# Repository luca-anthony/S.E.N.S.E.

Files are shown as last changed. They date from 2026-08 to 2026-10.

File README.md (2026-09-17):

<h1>ABSTRACT</h1>

This project started when we were scrambling for ideas for the Science Fair. We weren’t exactly sure what we were going to do. We considered projects on radiation, contamination, and physics. We just weren’t sure what to do. We thought of our past experiences and what we could turn into a project that could help someone. One of our team members was blind for a certain amount of time. They had a hard time navigating through the world and even just picking things up without knocking them over. We thought about how many other people must deal with these problems, so we came up with an idea to fix it. We thought of a wearable device that would be able to help people overcome these obstacles. So we made S.E.N.S.E. Using ToF sensors, IMUs, and a microcontroller, we were able to fit a device that can help people navigate through the world and their home that is just the size of a glove. So with this, we present S.E.N.S.E., Spatial Echo Navigation & Sensing Equipment. The tool you can use to travel the world, that is just the size of your hand.

<h1>How to Use</h1>

If you want to make this yourself, should you see this, or if you just want to do something for fun, this is how. 

<h4>For Raspberry Pi Zero 2 W</h4>
Commands for Pi: 

sudo apt update && sudo apt install git -y \
git clone https://github.com/luca-anthony/S.E.N.S.E./ \
cd S.E.N.S.E./Code/Bash && chmod +x setup.sh && ./setup.sh 

After installing everything, look in the Code/Python for the config.py file and follow the steps for wiring.

<h4>NOTE:</h4>

The team has decided against using the Raspberry Pi Zero 2 W.\
Any code or files for this Micro-Computer is not going to be updated as of 11 September 2026.

<h1>Contributions and Thanks</h1>

<h4>Donations and Funding</h4>

Logan Anthony - $30 \
(DEV) Kumar Nandi - $50 \
(DEV) Lou Anthony - $50 \
Reese Green - $1

To all of the people who donated or contributed to the project and or ENLIGHTEN, from the bottom of our hearts, <i>thank you</i>.

We are ENLIGHTEN. \
To bring more light to the world. 

<h1>STUFF FOR SCIENCE FAIR</h1>

<b>This section is irrelevant to anyone who is not a student or teacher at our school or who is not a direct contributor to S.E.N.S.E.</b>

Below is the link to the Science Fair Submission Form: \
<a href="https://docs.google.com/document/d/1qRC2OpuflSs2WIL9HmuddMR0fpJTnckwT1Jk4RrbsxM/edit?usp=sharing">Document</a>

Below is the link to the Final Research Paper and the drafts. \
<a href="https://docs.google.com/document/d/1NYGTEB_40bhyAXyYJ5kPaozn24XC8YlPzl25bhtnPuw/edit?usp=sharing">Document(s)</a>

If you want to donate or look in funding parts of this project text or call +1 (210) 865-7632 to discuss the matter.

<h4>Developers</h4>

Lou O. Anthony, lead scientist, lead computer scientist, assistant engineer, \
Kumar Nandi, lead engineer, lead 3D and 2D modeler, assistant computer scientist, \
Ty L. Garay, lead visionary, assistant 3D and 2D modeler, assistant engineer

<h1>EXTRAS</h1>

The website is no longer being updated as of 6 September 2026. \
It was purely a fun break for the team, not actually meant to present information.

<b>In Loving Memory of Anthony Garay</b> \
<b>You would’ve loved this</b>

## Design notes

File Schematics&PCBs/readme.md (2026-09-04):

Meant for schematics and PCBs. Pretty self explanatory.

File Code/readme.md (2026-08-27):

The C and C++ directories are meant for if we use the XIAO ESP32 C3\
The Python directory is meant for if we use the Raspberry Pi 2 Zero W

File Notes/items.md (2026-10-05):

REMOVED<sup>[1]</sup>\
VL53L1X<sup>[2]</sup> $14.99USD \
REMOVED<sup>[3]</sup> \
1027 Coin Cell Vibration Motor<sup>[4]</sup> $6.99USD \
2N2222 NPN Transistor(s)<sup>[5]</sup> $9.99USD \
1kΩ Resistor<sup>[6]</sup> $3.99USD \
LSM6DS3TR-C IMU unit<sup>[7]</sup> $9.95USDx2 \
1N4001 Diode<sup>[8]</sup> $4.74USD \
Raspberry Pi Pico<sup>[9]</sup> $9.99USD\
Sunlu TPU 95A Filament<sup>[10]</sup> $30.99USD \
Sunlu ASA Filament<sup>[11]</sup> $25.99USD \
Winfox 3.7V 2000mAh 803040 LiPo Battery<sup>[12]</sup> $7.99USDx2 \
Bourns Inc. MF-R050-ND PPTC Fuse<sup>[13]</sup> $9.99USD \
WWZMDiB 840 Pin Breadboard Jumper Wires Kit<sup>[14]</sup> $8.99USD \
Rindion 32 Pcs PCB Boards<sup>[15]</sup> $7.99USD\
Soldering Iron and Solder of your choice \
3D Printer of your choice (enclosed printer or enclosure recommended)

<h3>TOTAL</h3>

$172.92 USD (Not including tax or shipping) \
$118.54 USD (Without filament, Not including tax or shipping)

<a href="">REMOVED<sup>[1]</sup></a>\
<a href="https://www.amazon.com/dp/B09V4DS888?lv=shuf&channelId=500&plpRedirect=mhFallback">Distance sensors<sup>[2]</sup>\
<a href="">REMOVED<sup>[3]</sup><la>\
<a href="https://www.amazon.com/dp/B0993GDD7N?ref=clp_hp_h_pc&th=1">1027 Coin Cell Vibration Motor<sup>[4]</sup></a>\
<a href="https://www.amazon.com/BOJACK-General-Purpose-Transistors-Assortment/dp/B07T61SY9Y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">2N2222 NPN Transistor<sup>[5]</sup></a>\
<a href="https://www.amazon.com/California-JOS-Tolerance-Resistor-Resistance/dp/B0BDKV2TY5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">1kΩ Resistor<sup>[6]</sup>\
<a href="https://www.adafruit.com/product/4503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">IMU unit<sup>[7]</sup></a>\
<a href="https://www.amazon.com/EEEEE-1N4001-Rectifier-Electronic-Silicon/dp/B0FC2CTBJR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">1N4001 Diode<sup>[8]</sup></a>\
<a href="https://www.amazon.com/Raspberry-Pi-Pico/dp/B09KVB8LVR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">Raspberry Pi Pico<sup>[9]</sup></a>\
<a href="https://www.amazon.com/SUNLU-TPU-Filament-1-75mm-Flexible/dp/B0BXNWK6NS?th=1">Sunlu TPU 95A filament<sup>[10]</sup></a>\
<a href="https://www.amazon.com/SUNLU-ASA-Filament-3D-Printer/dp/B0B18CQGQJ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">Sunlu ASA filament<sup>[11]</sup></a> \
<a href="https://www.amazon.com/Winfox-Rechargeable-Connector-Bluetooth-Portable/dp/B0GDQVRHHZ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">Battery<sup>[12]</sup></a> \
<a href="https://www.amazon.com/gp/product/B085RDTCCV/ref=sw_img_1?smid=&th=1">Fuses<sup>[13]</sup></a> \
<a href="https://www.amazon.com/gp/product/B0BWGZRGYP/ref=ewc_pr_img_2?smid=A1YZW40LYQY3L1&psc=1">Wires<sup>[14]</sup></a> \
<a href="https://www.amazon.com/gp/product/B0DBZ1BXFZ/ref=ewc_pr_img_1?smid=A1Z1ENBD0KSZ4W&psc=1">PCBs<sup>[15]</sup></a>

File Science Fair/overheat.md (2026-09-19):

To ensure that the device would not overheat and harm the user, we thought of many things that could happen, including overheating due to air temperature, magnetic fields, and in case it touched something hot. Below is the math we used to ensure overheating would not happen. For this, we mainly used Maxwell's equations.

$$P = I^2 R \qquad B = \frac{\mu_0 I}{2\pi r} \qquad P_{\text{net}} = \epsilon\sigma A(T_{\text{source}}^4 - T_{\text{cap}}^4)$$

$$I = 0.015 \qquad T_{\text{source}} = 318.15 \qquad T_{\text{cap}} = 218.15 \qquad A = 4.9 \times 10^{-5}$$

$$B = \frac{(4\pi 10^{-7})0.015}{2\pi 0.003} \approx 6.67 \times 10^{-6} \text{ Tesla }(0.066 \text{ Gauss})$$

$$P_{\text{net}} = 0.09(5.67 \times 10^{-8}) \times (4.9 \times 10^{-5}) \times (318.15^4 - 218.15^4)$$

$$P_{\text{net}} \approx 5.9 \times 10^{-6} \text{ Watts }(5.9\mu\text{w})$$

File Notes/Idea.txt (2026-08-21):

PROJECT TITLE: HaptiSight - Multi-Array Wearable Spatial-Depth-to-Tactile Interface for Visually Impaired Navigation

1. PROJECT OVERVIEW AND HYPOTHESIS
Standard white canes and guide dogs leave a critical gap: they primarily identify ground-level obstacles directly in front of the user. Head-height hazards (low tree branches, signposts, open cabinet doors, suspended overhangs) remain undetectable until contact occurs. Existing electronic travel aids (ETAs) often rely on single-point ultrasonic sensors that trigger audio beeps. Audio alerts pollute critical environmental hearing cues, while single-point measurements fail to convey spatial context or object geometry.

This project develops an integrated wearable system (a chest harness or forearm sleeve) featuring a 3x3 matrix of Time-of-Flight (ToF) distance sensors paired with a corresponding 3x3 matrix of haptic vibration motors. By mapping 3D spatial depth arrays into real-time tactile intensity and frequency patterns on the skin, the device translates environmental geometry into touch perception without requiring visual sight or compromising hearing.

Hypothesis: Implementing a non-linear, edge-detecting haptic mapping algorithm will reduce obstacle navigation times and collision frequencies by at least 40% compared to traditional linear single-sensor distance-to-vibration feedback mechanisms.

2. HARDWARE AND SYSTEM ARCHITECTURE (ENGINEERING TEAM)
The engineering team handles component selection, power distribution, circuit design, signal multiplexing, and wearable ergonomics.

A. Microcontroller Unit (MCU):

* Primary MCU: ESP32-S3 or Teensy 4.1. Preferred due to high clock speeds, hardware I2C/SPI buses, low power consumption, and dual-core processing capabilities (allowing core 0 to process sensor inputs while core 1 manages haptic motor outputs).

B. Sensor Matrix (3x3 Grid):

* Sensor Type: VL53L1X Time-of-Flight (ToF) laser-ranging sensors (or Ultrasonic JSN-SR04T / MB1010 for wider cone sensing).
* Arrangement: 3 rows by 3 columns mounted on a rigid/flexible chest matrix covering three elevation zones:
* Top Row (3 sensors): Overhead and head-height field-of-view (1.5 m to 2.2 m above ground).
* Middle Row (3 sensors): Mid-torso and waist-height field-of-view (0.7 m to 1.5 m).
* Bottom Row (3 sensors): Low-level hazards, steps, and curbs (0 m to 0.7 m).

* Multiplexing: Since VL53L1X sensors share a default I2C address, use a TCA9548A 8-channel I2C multiplexer (or two multiplexers daisy-chained) to query each sensor rapidly without address conflicts.

C. Haptic Actuator Array:

* Motors: Linear Resonant Actuators (LRAs) or Eccentric Rotating Mass (ERM) coin vibration motors (e.g., 10mm x 2.0mm).
* Drivers: DRV2605L haptic motor driver chips connected via I2C, or transistor/MOSFET driver arrays (e.g., ULN2003 or custom MOSFET gates) controlled via Pulse-Width Modulation (PWM).
* Layout: Worn against a skin surface with high tactile resolution, such as the inner forearm, upper chest, or upper back.

D. Power Management & Mechanicals:

* Power: 3.7V LiPo battery (2000mAh+) feeding a step-up/step-down buck boost regulator supplying clean 3.3V and 5.0V rails.
* Chassis: Custom 3D-printed modular sensor housing featuring 15-degree angled mounts for the top and bottom sensor rows to maximize vertical field-of-view.

3. SOFTWARE AND ALGORITHMIC DESIGNS (CODING TEAM)
The coding team handles signal acquisition, noise filtering, spatial algorithms, and haptic rendering curves.

A. Data Pipeline and Filtering:

1. Matrix Polling: Continuous sequential polling of all 9 sensors via the I2C multiplexer at a target refresh rate of 30 Hz to 50 Hz.
2. Noise Suppression: Apply a moving median filter combined with a low-pass exponential filter to remove false reflections, specular noise, and outdoor sun-glare anomalies.

B. Experimental Feedback Algorithms (To Be Compared):

* Mode 1: Linear Direct Distance Mapping
* Formula: V_out = V_max * (1 - (D_measured / D_max))
* Vibration intensity scales proportionally with distance. Simple, but quickly leads to skin desensitization.

* Mode 2: Logarithmic Skin-Adapted Scaling
* Human tactile perception follows Weber-Fechner laws (non-linear sensitivity).
* Formula: V_out = V_max * (log(D_max / max(D_measured, D_min)) / log(D_max / D_min))
* Provides subtle feedback for distant objects while rapidly ramping up intensity as an obstacle enters the immediate safety zone (under 1 meter).

* Mode 3: Velocity-Sensitive Closure Rate Mode
* Calculates delta distance over time (dD/dt).
* Actuators remain silent for stationary distant objects, but activate with high intensity if the rate of closure toward an obstacle indicates imminent collision.

* Mode 4: Spatial Edge & Silhouette Detection
* The MCU calculates spatial gradients across neighboring matrix cells: G_x = |D(x+1, y) - D(x, y)| and G_y = |D(x, y+1) - D(x, y)|.
* Vibrate actuators only where a significant depth discontinuity occurs, allowing the wearer to feel the boundary, door opening, or outline of an object.

4. EXPERIMENTAL TESTING METHODOLOGY (SCIENCE FAIR DATA)
To qualify as an advanced science fair submission, quantitative performance metrics must be collected across multiple experimental trials.

A. Variables:

* Independent Variable: Haptic algorithm type (Linear, Logarithmic, Velocity-Sensitive, Edge-Detection) and sensor configuration.
* Dependent Variables:
1. Time to navigate a standardized 15-meter obstacle course (seconds).
2. Total number of physical collisions (head, torso, ground).
3. Spatial recognition accuracy (percentage of correct identification of mock obstacles: doorway, pole, low hanging branch, box on floor).

* Controlled Variables: Course layout, obstacle dimensions, walking path width, ambient lighting, and ear protection/masking noise worn by subjects to prevent reliance on acoustic echoes.

B. Testing Protocol:

1. Construct a standardized, repeatable indoor/outdoor maze containing 10 hazards (3 head-height, 4 torso-height, 3 ground-level).
2. Run trials with blindfolded test participants across each feedback mode (minimum 10 trials per mode per participant).
3. Record time, collisions, and subjective spatial mapping accuracy ratings.
4. Calculate statistical significance using ANOVA or paired T-tests to determine which algorithm offers the best balance of speed, safety, and cognitive load reduction.
5. REQUIRED COMPONENTS AND SHOPPING LIST

* Microcontroller: ESP32-S3 Dev Board or Teensy 4.1
* Distance Sensors: 9x VL53L1X Time-of-Flight sensors
* I2C Multiplexer: 2x TCA9548A modules
* Haptic Drivers: 9x DRV2605L breakout boards (or custom MOSFET driver board)
* Haptic Motors: 9x ERM coin vibration motors (10mm)
* Power: 3.7V 2500mAh LiPo battery + TP4056 charging board + 5V step-up boost converter
* Framing: Flexible chest harness/vest, 3D printing filament (PLA/TPU), jumper wires, breadboards/perfboards

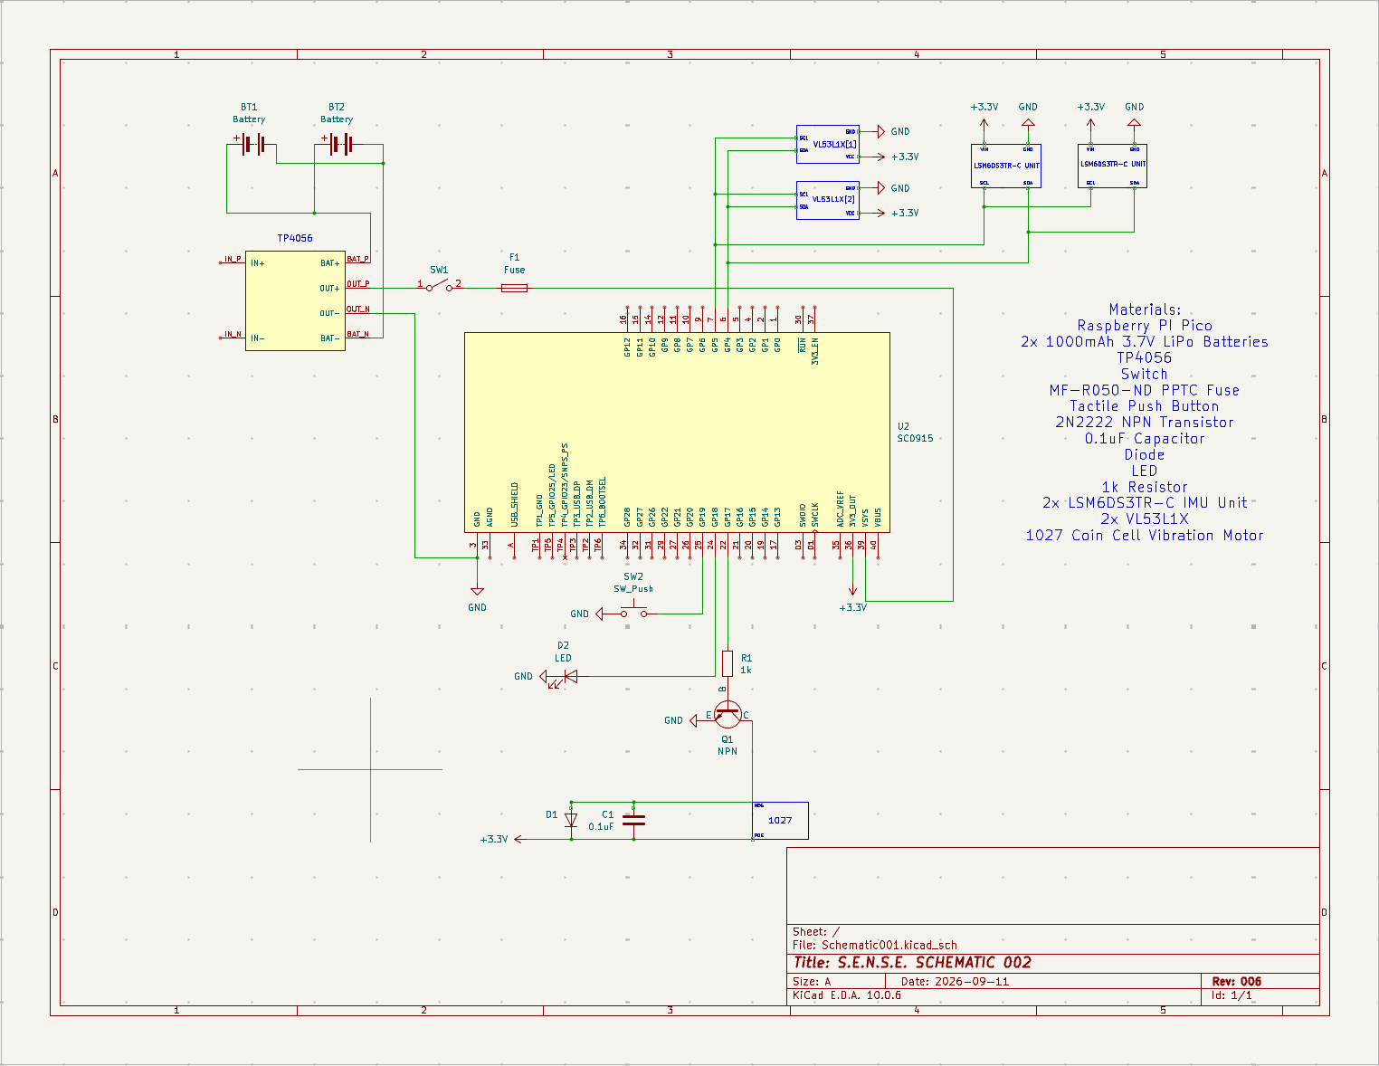
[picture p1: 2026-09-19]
Schematics&PCBs/Schematic001/schematic001_kicad_Schematic001.png

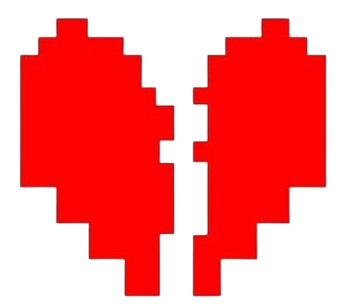
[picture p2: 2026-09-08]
Website/assets/heart_broken.png

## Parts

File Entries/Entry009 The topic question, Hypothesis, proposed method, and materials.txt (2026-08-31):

We need to discuss quite a few things. 
The topic question/problem, hypthesis, proposed method, and materials. 
Let's start with the topic question/problem. 

Humans who have visual impairment struggle with picking things up walking or normal functions. 
About half of the human brain works to process visual information. 
With visual impairment, things like walking and even picking things up. 
We want to solve that.
So that is our problem. How can we better help that part of the community with visual impairments?

Let's move to the Hypothesis. 
Since we decided to use coin cell vibration sensors to help direct people, how can the sensors and motors help people?
I created a few hypotheses. 

If the human body can detect vibrations, then can they use vibrations to navigate and do tasks? 

Now lets talk about our proposed method.
Entry No.4 talks about the proposed method of testing.
I think the best thing is to test both. 
If we test in both ways we not only test how to walk, but also tasks like picking things up. 
Therefore we need to test not just idea No. 1 but also idea No.2. 

Now, the designing. 
In the notes section we have the items list. 
The most expensive thing is the filaments. 
In total with our current items list, we are running about 50-80 dollars. 
This means that this is within our budget.
  As for designing it, that will be done in Fusion360 in a free plan. 
They will be printed on two Bambu Lab printers. 

Conclusion: This project is within our budget, easily doable and definetly will help a lot of people. 

Kumar N. -Lead 3d modeler, lead engineer, assistant computer scientist.

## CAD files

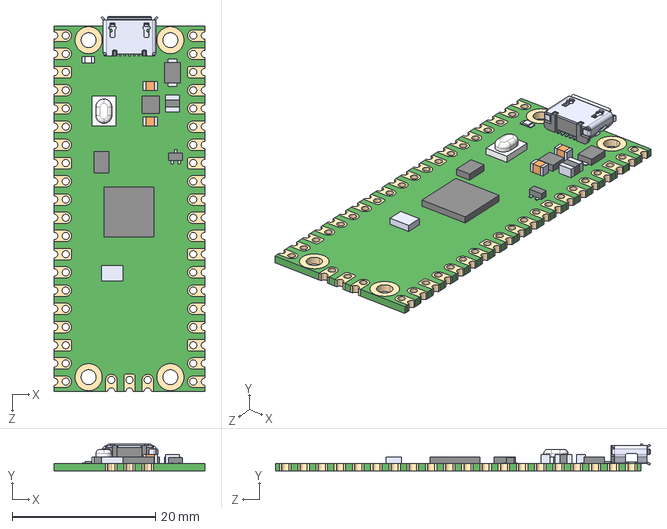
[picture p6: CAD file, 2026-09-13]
Schematics&PCBs/Schematic001/SC0915 - RPP/SC0915.step
21.0 x 3.73 x 52.3 mm

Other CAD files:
Models/Model 5.f3d
Models/Wristband Model 3.f3d
Models/Wristband Model 4.f3d
Models/Wristband and components model 2.f3d
Models/wristband and components.f3d

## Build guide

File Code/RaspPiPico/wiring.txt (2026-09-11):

==================================
        PICO 2 W WIRING CHART
==================================

----------------------------------
      POWER & I2C SHARED BUS
----------------------------------
* I2C Bus: Using I2C0 hardware bus.
  - SDA (GP4) and SCL (GP5) are shared across the VL53L1X, 
    IMU #1, and IMU #2 in parallel.
* Power Rails:
  - 3.3V Rail: Pin 36 (3V3 OUT)
  - 5V Rail: Pin 40 (VBUS - raw USB 5V for motor)
  - GND Rail: Any GND pin (Pins 3, 8, 13, 18, 23, 28, 33, 38)

----------------------------------
              VL53L1X
----------------------------------
VCC --> Pin 36 / 3V3 OUT
GND --> Pin 3  / GND
SDA --> Pin 6  / GP4 (I2C0 SDA)
SCL --> Pin 7  / GP5 (I2C0 SCL)

----------------------------------
        IMU #1 (Hand Back)
----------------------------------
VCC --> Pin 36 / 3V3 OUT
GND --> Pin 8  / GND
SDA --> Pin 6  / GP4 (I2C0 SDA)
SCL --> Pin 7  / GP5 (I2C0 SCL)
AD0 --> Pin 8  / GND            (Sets I2C Address to 0x68)

----------------------------------
        IMU #2 (Finger Tip)
----------------------------------
VCC --> Pin 36 / 3V3 OUT
GND --> Pin 13 / GND
SDA --> Pin 6  / GP4 (I2C0 SDA)
SCL --> Pin 7  / GP5 (I2C0 SCL)
AD0 --> Pin 36 / 3V3 OUT        (Sets I2C Address to 0x69)

----------------------------------
      MOTOR / TRANSISTOR / DIODE
----------------------------------
----TRANSISTOR (NPN / e.g. PN2222)
EMITTER   --> Pin 18 / GND
BASE      --> 1K Resistor
1K R      --> Pin 22 / GP17 (PWM control)
COLLECTOR --> MOTOR NEG / DIODE ANODE

----DIODE (Flyback)
CATHODE   --> Pin 40 / VBUS (5V USB Power)
ANODE     --> COLLECTOR / MOTOR NEG

----MOTOR (ERM Vibration Coin)
POS       --> Pin 40 / VBUS (Connected to Diode Cathode)
NEG       --> COLLECTOR / DIODE ANODE

----------------------------------
            STATUS LED
----------------------------------
ANODE (+) --> 220Ω Resistor
220Ω R    --> Pin 24 / GP18
CATHODE(-)--> Pin 23 / GND

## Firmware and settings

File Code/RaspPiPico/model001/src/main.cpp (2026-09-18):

#include <Arduino.h>
#include <Wire.h>
#include <Adafruit_VL53L1X.h>
#include <Preferences.h>
#include "SparkFunLSM6DS3.h"

//======================
// INPUTS AND VARIABLES
//======================
const int MOT_IO = 17;
const int LED_IO = 18;
const int BTN_IO = 19;

const int DIST_THRESH = 100;
const int16_t CHANGE_THRESH = 196;

const int MOT_MIN_PWM = 100;
const int MOT_MAX_PWM = 255;

const unsigned long SENSOR_INTERVAL_MS = 50;   // how often to poll sensors
const unsigned long DEBOUNCE_MS        = 200;  // button debounce window
const float DISTANCE_SMOOTHING_ALPHA   = 0.35; // 0=very smooth/slow, 1=raw/instant

#define IRQ_PIN -1
#define XSHUT_PIN -1

#undef Wire
arduino::MbedI2C Wire(4, 5);

Adafruit_VL53L1X sensor = Adafruit_VL53L1X();

//======================
//       GLOBALS
//======================
Adafruit_VL53L1X vl53 = Adafruit_VL53L1X(XSHUT_PIN, IRQ_PIN);
LSM6DS3 myIMU(I2C_MODE, 0x6A);
Preferences prefs;

int mode = 1; // 1 = navigation, 2 = close-range
float smoothedDistanceCM = -1;      // -1 means "no valid reading yet"

unsigned long lastSensRead = 0;
unsigned long lastDebounceTime = 0;
int16_t distance = 0;

int lastButtonReading = HIGH; // pull=up idle state
int lastButtonState = HIGH; 

//---------------------------------------------------------------
// Haptic feedback patterns
// Kept short/blocking since these only fire on discrete events
// (boot, mode switch), not during normal obstacle sensing.
//---------------------------------------------------------------
void buzz(int durationMs, int intensity = MOT_MAX_PWM) {
  analogWrite(MOT_IO, intensity);
  delay(durationMs);
  analogWrite(MOT_IO, 0);
}

void buzzPattern(int count, int durationMs = 120, int gapMs = 120) {
  for (int i = 0; i < count; i++) {
    buzz(durationMs);
    if (i < count - 1) delay(gapMs);
  }
}

// One buzz = mode 1 (navigation), two buzzes = mode 2 (close-range).
void announceMode() {
  buzzPattern(mode);
}

// Distinct longer pattern on boot so the wearer knows the device is alive
// and the distance sensor initialized correctly, without needing Serial.
void announceReady() {
  buzzPattern(3, 80, 80);
}

// A different, more urgent-feeling pattern to signal a hardware problem
// (sensor failed to initialize) so the wearer isn't left guessing why
// nothing is working.
void announceError() {
  buzz(600);
}

//======================
//      INIT IMUs
//======================
// Instantiate the IMU object. 
// 0x6A is the standard address for most breakout boards.
void initIMU() {
    if (myIMU.begin() != 0) {
        Serial.println("IMU Error! Check wiring or I2C address.");
        announceError();
    } else {
        Serial.println("LSM6DS3TR-C Successfully Connected!");
    }
}

//======================
//  MODE SWITCH LOGIC
//======================
void modeSwitch() {
  int reading = digitalRead(BTN_IO);

  if (reading != lastButtonState) {
    lastDebounceTime = millis();
  }

  if ((millis() - lastDebounceTime) > DEBOUNCE_MS) {
    // If the button state has stably changed to LOW (pressed)
    if (reading == LOW && lastButtonState == HIGH) {
      // Toggle mode between 1 and 2
      mode = (mode == 1) ? 2 : 1;
      
      Serial.print("Mode changed to: ");
      Serial.println(mode);
      
      // Save the preference permanently
      prefs.putUChar("mode", mode);
      
      // Provide feedback
      announceMode();
    }
  }

  lastButtonState = reading;
}

//======================
//     INIT VL53L1X
//======================
Adafruit_VL53L1X vl53 = Adafruit_VL53L1X(XSHUT_PIN, IRQ_PIN);
void initVL53L1X() {
  Serial.println(F("Initializing VL53L1X..."));
  if (!vl53.begin(0x29, &Wire)) {
    Serial.print(F("Error on initializing VL53L1X sensor: "));
    Serial.println(vl53.vl_status);
    while (1) delay(10);
  }
  Serial.println(F("VL53L1X OK!"));
  
  if (!vl53.startRanging()) {
    Serial.print(F("Couldn't start ranging: "));
    Serial.println(vl53.vl_status);
    while (1) delay(10);
  }
  
  // Timing budget options: 15, 20, 33, 50, 100, 200 ms
  vl53.setTimingBudget(SENSOR_INTERVAL_MS);
}

//======================
//    VL53L1X LOGIC1
//======================
void VL53L1XLogic1() {
  static int16_t lastDistance = -1; 

  if (distance != -1) {
    if (lastDistance != -1) {
      int16_t difference = abs(distance - lastDistance);
      if (difference > CHANGE_THRESH) {
        buzz(10, 255);
      }
    }
    lastDistance = distance; // Update state for next calculation
  }
}

//======================
//    VL53L1X LOGIC2
//======================
void VL53L1XLogic2() {
  Serial.println(F("RUNNING VL53L1X LOGIC FOR MODE 2"));

  int difference = DIST_THRESH - distance;

  // Closer than threshold
  if (difference > 0) {
    // Clamp difference to a max limit so mapping stays within expected bounds
    int constrainedDiff = constrain(difference, 0, DIST_THRESH);

    // As distance gets closer (difference increases):
    // - count increases (e.g., 1 to 5 pulses)
    // - duration increases (e.g., 50ms to 200ms per pulse)
    // - gap decreases (e.g., 200ms down to 30ms between pulses for higher frequency)
    int count = map(constrainedDiff, 0, DIST_THRESH, 1, 5);
    int duration = map(constrainedDiff, 0, DIST_THRESH, 50, 200);
    int gap = map(constrainedDiff, 0, DIST_THRESH, 200, 30);

    buzzPattern(count, duration, gap);
  }

}

//======================
//        SETUP
//======================
void setup() {
  Serial.begin(115200);

  // Set Pin-Modes
  pinMode(MOT_IO, OUTPUT);
  pinMode(LED_IO, OUTPUT);
  pinMode(BTN_IO, INPUT_PULLUP);

  Wire.begin(); // Initialize I2C communication

  // Initialize DISTSENS' and IMUs
  initVL53L1X();
  initIMU();

  // Restore last-used mode so the wearer doesn't have to re-select it
  // every time the device powers on.
  prefs.begin("sense", false);
  mode = prefs.getUChar("mode", 1);

  announceReady();
}

//======================
//        LOOP
//======================
void loop() {
  // Check Mode
  modeSwitch();

  // Poll distance sensor when data is available
  if (vl53.dataReady()) {
    distance = vl53.distance();
    vl53.clearInterrupt();

    // Mode 1
    if (mode == 1) {
      VL53L1XLogic1();
    // Mode 2
    } else if (mode == 2) {
      VL53L1XLogic2();
    }
  }
}

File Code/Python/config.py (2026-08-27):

"""
S.E.N.S.E. -- config.py
 
All pin numbers and tunable thresholds live here, and nowhere else.
If you're calibrating the device for a new user or swapping hardware,
this is the only file you should need to touch.
"""

import os

# =================================
#          SETUP COMMANDS 
# =================================
"""
sudo raspi-config nonint do_i2c 0
sudo raspi-config nonint do_spi 0
sudo apt update
sudo apt install -y python3-pip python3-smbus i2c-tools
sudo apt install -y python3-gpiozero python3-spidev
pip3 install adafruit-circuitpython-vl53l1x adafruit-blinka
sudo apt install -y pigpio python3-pigpio
sudo systemctl enable pigpiod
sudo systemctl start pigpiod
sudo reboot
"""

# ==================================
#              WIRING
# ==================================
#
# ----------------------------------
#             VL53L1X
# ----------------------------------
# VCC --> Pin 1/5V/3.3V
# GND --> Pin 9/GND
# SDA --> Pin 3/GPIO2
# SCL --> Pin 5/GPIO3
#
# ----------------------------------
#       FLEX SENSOR & MCP3008
# ----------------------------------
# ----MCP3008
# VDD/Pin 16  --> Pin 1/3.3v
# VREF/Pin 15 --> Pin 1/3.3v
# AGND/Pin 14 --> Pin 6/GND
# DGND/Pin 9  --> Pin 6/GND
# CS/SHDN/Pin 10 --> Pin 24/GPIO 8/CE0
# DIN/MOSI/Pin 11 --> Pin 19/GPIO 10/MOSI
# DOUT/MISO/Pin 12 --> Pin 21/GPIO 9/MISO
# CLK/Pin 13  --> Pin 23/GPIO 11/SCLK
# CH0/Pin 1   --> 10K R & FLEX-SENS GND
#
# ----FLEX SENSOR
# VCC --> Pin 1/3.3v
# GND --> 10K R
# 10K R --> Pin 6/GND
#
# ----------------------------------
#      MOTOR/TRANSISTOR/DIODE
# ----------------------------------
# ----TRANSISTOR
# EMITTER --> Pin 6/GND
# BASE --> 1K R
# 1K R --> Pin 11/GPIO 17
# COLLECTOR --> NEG
#
# ----DIODE
# CATHODE --> 3.3V/Meet With Positive Motor Line
# ANODE --> COLLECTOR
#
# ----MOTOR
# POS --> CATHODE/3.3V
# NEG --> COLLECTOR
#
# ----------------------------------
#          MODE BUTTON
# ----------------------------------
# Not in the original build -- added for mode switching (nav vs close-range).
# One leg --> GPIO27 (Pin 13)
# Other leg --> Pin 6/GND
# gpiozero's Button uses an internal pull-up, so no resistor needed.

# ==================================
#                PINS
# ==================================

MOT_PIN = 17
BTN_PIN = 27
FLEX_CHANNEL = 0

# ==================================
#  THRESHOLDS (calibrate per user)
# ==================================

FLEX_THRESH = 0.4 # Hand flat threshold, 0.0-1.0
DIST_THRESH_CM1 = 80 # Mode 1: General Navigation
DIST_THRESH_CM2 = 4 # Mode 2: close object/grabbing range

MOT_MIN = 0.4 # Floor so weak motors actually kick on (0.0-1.0)
MOT_MAX = 1.0 # Max Vibration Intensity

SENS_INTERVALS = 0.05 # Poll sensors ever 50ms
DEBOUNCES = 0.2 # Button debounce window
DIST_SMOOTHING_ALPHA = 0.35 # 0=very smooth/slow, 1=raw/instant

# Where the current selected mode is across reboots

MODE_FILE = os.path.join(os.path.dirname(os.path.abspath(__file__)), "sense_mode.json")

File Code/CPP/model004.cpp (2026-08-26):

// ============================================================================
// S.E.N.S.E. — Spatial Echo Navigation & Sensing Equipment
// model004.cpp — builds on model003, fixes compile bugs + adds UX features
//
// Hardware: Seeed XIAO ESP32-C3, VL53L0X ToF distance sensor, flex sensor,
//           coin vibration motor (via NPN transistor), mode push button
// ============================================================================

#include <Arduino.h>
#include <Wire.h>
#include <Adafruit_VL53L0X.h>
#include <Preferences.h>   

// ============================================================================
// INPUTS AND VARIABLES - Some need to be calibrated
// ============================================================================
const int FLEX_PIN         = A0;   // Flex sensor analog input
const int MOT_PIN          = 9;    // PWM output to motor transistor
const int BTN_PIN          = 2;    // Mode switch button (INPUT_PULLUP)

const int FLEX_THRESH      = 500;  // Hand-flat threshold — calibrate per user
const int DIST_THRESH_CM1  = 80;   // Mode 1: general navigation range
const int DIST_THRESH_CM2  = 4;    // Mode 2: close-object / grabbing range

const int MOTOR_MIN_PWM    = 100;  // Floor so weak motors reliably kick on
const int MOTOR_MAX_PWM    = 255;  // Max vibration intensity

const unsigned long SENSOR_INTERVAL_MS = 50;   // how often to poll sensors
const unsigned long DEBOUNCE_MS        = 200;  // button debounce window
const float DISTANCE_SMOOTHING_ALPHA   = 0.35; // 0=very smooth/slow, 1=raw/instant

// ============================================================================
// Globals
// ============================================================================
Adafruit_VL53L0X lox = Adafruit_VL53L0X();
Preferences prefs;

int mode = 1;                       // 1 = navigation, 2 = close-range
float smoothedDistanceCM = -1;      // -1 means "no valid reading yet"

unsigned long lastSensorRead = 0;
unsigned long lastDebounceTime = 0;
int lastButtonReading = HIGH;       // pull-up idle state

// ============================================================================
// Haptic feedback patterns
// Kept short/blocking since these only fire on discrete events
// (boot, mode switch), not during normal obstacle sensing.
// ============================================================================
void buzz(int durationMs, int intensity = MOTOR_MAX_PWM) {
  analogWrite(MOT_PIN, intensity);
  delay(durationMs);
  analogWrite(MOT_PIN, 0);
}

void buzzPattern(int count, int durationMs = 120, int gapMs = 120) {
  for (int i = 0; i < count; i++) {
    buzz(durationMs);
    if (i < count - 1) delay(gapMs);
  }
}

// One buzz = mode 1 (navigation), two buzzes = mode 2 (close-range).
void announceMode() {
  buzzPattern(mode);
}

// Distinct longer pattern on boot so the wearer knows the device is alive
// and the distance sensor initialized correctly, without needing Serial.
void announceReady() {
  buzzPattern(3, 80, 80);
}

// A different, more urgent-feeling pattern to signal a hardware problem
// (sensor failed to initialize) so the wearer isn't left guessing why
// nothing is working.
void announceError() {
  buzz(600);
}

// ============================================================================
// Distance sensor read, in cm. Returns -1 if the reading is invalid/out of range.
// ============================================================================
int getDistanceCM() {
  VL53L0X_RangingMeasurementData_t measure;
  lox.rangingTest(&measure, false);

  if (measure.RangeStatus == 4) {
    // 4 == "out of range" per the Adafruit VL53L0X library
    return -1;
  }
  return measure.RangeMilliMeter / 10;
}

// ============================================================================
// Non-blocking button handling. Toggles mode on a clean press, debounced
// with millis() instead of delay() so it never freezes the sensing loop.
// ============================================================================
void handleModeButton() {
  int reading = digitalRead(BTN_PIN);

  if (reading != lastButtonReading) {
    lastDebounceTime = millis();
  }

  if ((millis() - lastDebounceTime) > DEBOUNCE_MS) {
    // Button is pressed (active LOW) and this is a fresh state we haven't acted on
    if (reading == LOW && lastButtonReading == HIGH) {
      mode = (mode == 1) ? 2 : 1;
      Serial.print("Mode changed to ");
      Serial.println(mode);

      prefs.putUChar("mode", mode);  // remember it for next boot
      announceMode();                // and, more importantly, let the wearer feel it
    }
  }

  lastButtonReading = reading;
}

// ============================================================================
// Setup
// ============================================================================
void setup() {
  Serial.begin(115200);

  pinMode(FLEX_PIN, INPUT);
  pinMode(MOT_PIN, OUTPUT);
  pinMode(BTN_PIN, INPUT_PULLUP);

  // Restore last-used mode so the wearer doesn't have to re-select it
  // every time the device powers on.
  prefs.begin("sense", false);
  mode = prefs.getUChar("mode", 1);

  Serial.println("Initializing VL53L0X...");
  if (!lox.begin()) {
    Serial.println("Failed to find VL53L0X sensor!");
    announceError();
    while (1) {
      delay(1000);
    }
  }
  Serial.println("VL53L0X Initialized Successfully!");

  announceReady();
}

// ============================================================================
// Main loop — sensing runs on a timed interval (non-blocking), button
// handling runs every pass so mode switches feel instant.
// ============================================================================
void loop() {
  handleModeButton();

  unsigned long now = millis();
  if (now - lastSensorRead < SENSOR_INTERVAL_MS) {
    return;  // keeps loop responsive to the button
  }
  lastSensorRead = now;

  int flexVal = analogRead(FLEX_PIN);
  int activeThresh = (mode == 1) ? DIST_THRESH_CM1 : DIST_THRESH_CM2;

  // Hand curled/resting — system off to prevent false alerts
  if (flexVal <= FLEX_THRESH) {
    analogWrite(MOT_PIN, 0);
    smoothedDistanceCM = -1;  // reset filter so it doesn't carry stale data
    return;
  }

  // Hand flat — read and smooth the distance
  int rawDistance = getDistanceCM();

  if (rawDistance > 0) {
    smoothedDistanceCM = (smoothedDistanceCM < 0)
      ? rawDistance
      : (DISTANCE_SMOOTHING_ALPHA * rawDistance
         + (1 - DISTANCE_SMOOTHING_ALPHA) * smoothedDistanceCM);
  } else {
    smoothedDistanceCM = -1;
  }

  if (smoothedDistanceCM > 0 && smoothedDistanceCM < activeThresh) {
    int intensity = map((int)smoothedDistanceCM, activeThresh, 0, MOTOR_MIN_PWM, MOTOR_MAX_PWM);
    analogWrite(MOT_PIN, constrain(intensity, 0, MOTOR_MAX_PWM));
  } else {
    analogWrite(MOT_PIN, 0);
  }
}

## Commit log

2026-08-21 Created Notes and Entry001.txt (Empty currently)
2026-08-21 Created Notes Dir and Created Entry001.txt (Currently Empty)
2026-08-23 Add flowchart for sensor-based motor control
2026-08-23 Came up with example code (hopefully it works well)
    This code initializes a flex sensor and a motor control system, reading the flex sensor value and adjusting motor intensity based on the distance measured by a distance sensor.
    [example.c]
2026-08-23 Enhance README with project details and team information
    Expanded on the project's purpose and functionality, detailing how the device assists individuals with visual impairments. Included team member roles and aspirations for the project.
2026-08-24 Made official model001.c added mode switching with button
2026-08-24 Made Mode Switch into function and shortened code for thresh detection
    [model002.c]
2026-08-26 Added more notes and fixed up code. Added new functions as well.
    [model004.cpp]
2026-08-27 Add setup commands and wiring instructions
    Added setup commands and wiring instructions for VL53L1X, MCP3008, flex sensor, motor, transistor, and diode.
2026-08-27 Add Raspberry Pi Zero 2 W to items list
2026-08-27 Add wiring and setup commands for Raspberry Pi
    Added wiring instructions and commands for Raspberry Pi setup including sensor and motor connections.
2026-08-27 Update config.py with setup commands and wiring info
    Added configuration settings and wiring details for various components.
2026-08-31 Entry009.txt The topic question, Hypothesis, proposed method, and materials.
2026-08-31 Entry009.txt
    The topic question, Hypothesis, proposed method, and materials.
2026-09-04 Add readme for Schematics and PCBs
2026-09-06 Corrected Link for IMU
2026-09-06 Corrected Link for IMU x2
2026-09-07 Started making the website for S.E.N.S.E. (S.E.N.S.E. stands for "Some Extra Nice Stuff, Eh?"). The website will include a homepage, a code choice page, a contact page, and a determination page. The 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
2026-09-12 Model 3 for the new Raspberry Pi Pico
    [Wristband Model 3.f3d]
2026-09-13 Started Code for Pico and made Animation directory
    [SC0915.step, Schematic001.kicad_pcb, Schematic001.kicad_sch]
2026-09-13 Save schematic changes
2026-09-14 This is the model 4 with notches
    [Wristband Model 4.f3d]
2026-09-14 Update Wristband Model 4.f3d
    [Wristband Model 4.f3d]
2026-09-16 Model 5
    Added notches and 7 holes for cable management.
    [Model 5.f3d]
2026-09-16 Refactor IMU initialization and VL53L1X logic
2026-09-16 Add macOS setup script for development environment
    This script automates the setup of a macOS environment by installing Homebrew, core dependencies, Visual Studio Code, and the PlatformIO IDE extension. It also clones a Git repository and initializes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
2026-09-18 Clone for Drive
    [Model 5.f3d]
2026-09-18 Uploaded Schematic Image
2026-09-18 Rename Screenshot 2026-09-18 at 14.14.05.png to schematic001_kicad_Schematic001.png
2026-09-18 Add overheating prevention details to overheat.md
    Documented considerations and calculations to prevent device overheating.
2026-09-19 Update Schematic
2026-10-11 Created flex sensor code and monitor with modified wiring
2026-10-12 Added charger on items
2026-10-14 Whole New Schematic
2026-10-20 Made a PCB.
